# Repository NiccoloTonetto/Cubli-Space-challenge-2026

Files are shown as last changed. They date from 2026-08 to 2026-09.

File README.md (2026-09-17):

# Cubli — Space Challenge 2026

A 156 mm reaction-wheel cube that balances on an **edge** and on a **corner**,
taken from Lagrangian derivation through Simscape multibody simulation to
working hardware — and validated against its own flight telemetry.

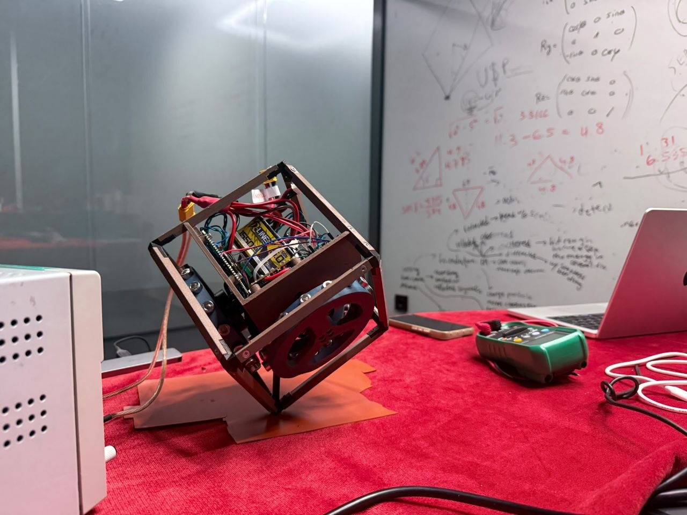
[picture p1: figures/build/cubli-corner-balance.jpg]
The cube balancing unsupported on one corner


*Standing on a single corner, unsupported. Three reaction wheels, a Teensy 4.1
closing a 400 Hz loop, and a gain set designed for this specific corner.*

And the telemetry underneath it — six minutes of exactly that, without falling:

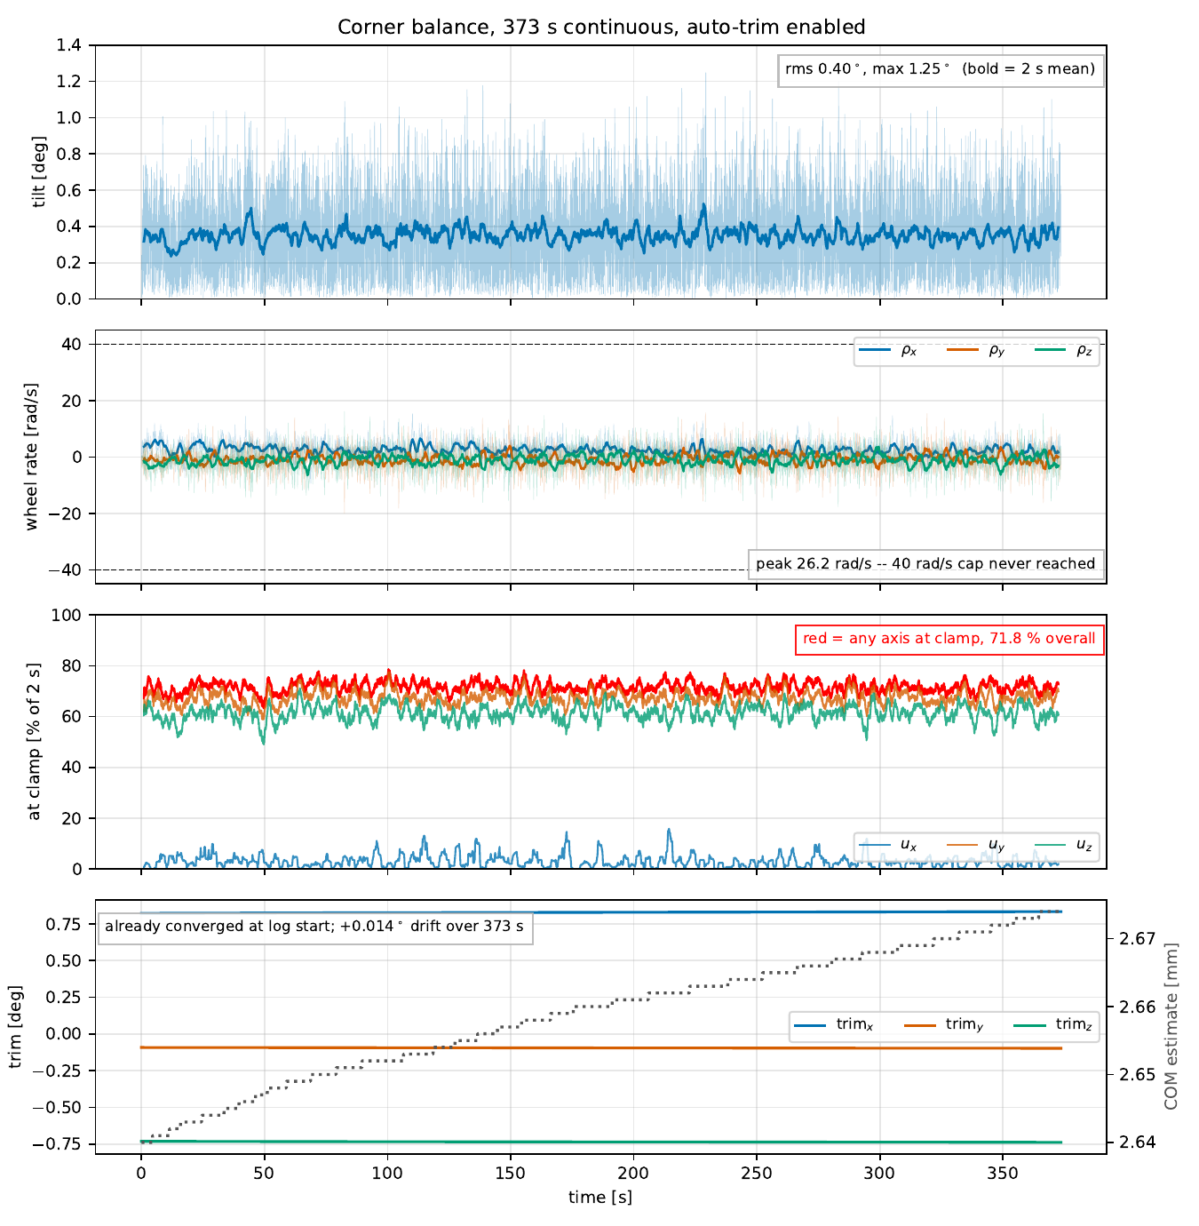
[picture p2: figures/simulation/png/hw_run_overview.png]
373 s of continuous corner balance


*373 s continuous. Tilt RMS 0.40°, peak 1.25°, wheels never reaching the
40 rad/s policy cap. Raw log:
[`data/corner/corner-balance-373s-2026-08-20.log`](data/corner/corner-balance-373s-2026-08-20.log).*

---

## What it achieves

| | Result | Source |
|---|---|---|
| **Corner balance, longest run** | **373.5 s continuous**, tilt RMS **0.40°**, max 1.25° | [log](data/corner/corner-balance-373s-2026-08-20.log) |
| **Corner balance, quietest run** | 278 s, tilt RMS **0.25°**, max 0.92° | [log](data/corner/FINAL_CALIBRATION.log) |
| **Edge balance** | **197 s continuous**, tilt RMS 0.58° | [log](data/edge/1minEDGE.log) · [report](docs/testing/Corner-RateFilter-and-Edge-Hardware-Tests-2026-08-19.md#4-edge--1-min-quiet-hold) |
| **Disturbance rejection** | recovers ~3° pushes in **0.08–0.20 s**; trips at the 25° policy limit | [report §3](docs/testing/Corner-RateFilter-and-Edge-Hardware-Tests-2026-08-19.md#3-pushes--how-hard-until-it-falls) |
| **Edge release** | recovers from **6.18°**, settles under 0.5° by 9.6 s | [report §5](docs/testing/Corner-RateFilter-and-Edge-Hardware-Tests-2026-08-19.md#5-edge--recovery-from-6) |
| **Predicted envelope** | 2.76°–3.14° worst-case recovery, all 8 corners | [envelope study](docs/dynamics/Cube-Performance-Envelope-Results.md#per-corner-results-own-gains-supersedes-part-2-3s-table) |

The hardware sits inside the envelope the simulation predicted, and the run above
is *momentum*-bound rather than torque-bound — exactly the binding constraint the
model identified before the cube was ever switched on.

## The system

| | |
|---|---|
| **Structure** | 156 mm printed PETG-CF frame, 1.615 kg assembled, 3 ballasted reaction wheels |
| **Actuation** | 3 × T-Motor Antigravity 4006 (Kt 0.02513 N·m/A) on 3 × [mjbots moteus-n1](https://mjbots.com) FOC drivers, 5 Mbps CAN-FD |
| **Sensing** | Bosch BMI270 IMU at the cube's geometric centre — 130 mm from *every* corner |
| **Compute** | Teensy 4.1 running the 400 Hz control loop; XIAO ESP32-C6 as a Wi-Fi telemetry bridge |
| **Estimator** | reduced-attitude complementary filter with gyro-bias states (`kP = 4`, `kI = 0.5`) |
| **Control** | per-corner and per-edge reduced-order LQR, yaw-projected — 8 corner gain sets, 12 edge gain sets |
| **Operating point** | τ_max 0.12 N·m, wheel-speed cap 40 rad/s (firmware policy, not a hardware limit) |

## The engineering story

**1 — Derive the plant.** The [3D Lagrangian derivation](docs/dynamics/3D-Cubli-Lagrangian-Derivation.md)
is worked from scratch and specialised to the 1D/2D edge case, with
[CAD → model parameters](docs/dynamics/Deriving-Dynamics-from-CAD.md) and an
[attitude-representation study](docs/dynamics/Quaternions-Complete-Guide.md)
that ends up rejecting quaternions for corner balance and choosing a reduced
attitude instead — [argued, not assumed](docs/dynamics/Attitude-Representation-for-Firmware.md).

**2 — Prove it on a 2D panel first.** A [Simscape panel model](docs/simulation/Simscape-Panel-Model-Build-Guide.md)
with four dedicated nonlinearity studies — [saturation envelope](docs/simulation/reports/Saturation-Envelope-Test-Block-A.md),
[discrete-loop delay](docs/simulation/reports/Discrete-Loop-Test-Block-B.md),
[IMU lever arm](docs/simulation/reports/IMU-Lever-Arm-Estimator-Block-C.md),
[friction sensitivity](docs/simulation/reports/Friction-Sensitivity-Block-D.md).
The [1D-jig-to-3D-cube strategy](docs/dynamics/1D-Jig-to-3D-Cube-Strategy.md)
states exactly what transfers and what does not.

**3 — Build the cube model three ways.** A 9-state linear design plant, a
Simscape multibody model built from imported STEP geometry, and a fast nonlinear
plant with sensors and actuator limits. They agree to
[`A err 1.7e-07`](docs/dynamics/Cube-Performance-Envelope-Results.md#validation-chain)
and within 1 % through the transient — which is what makes the thousands of
bisection runs behind the recovery envelope trustworthy.

<table>
<tr>
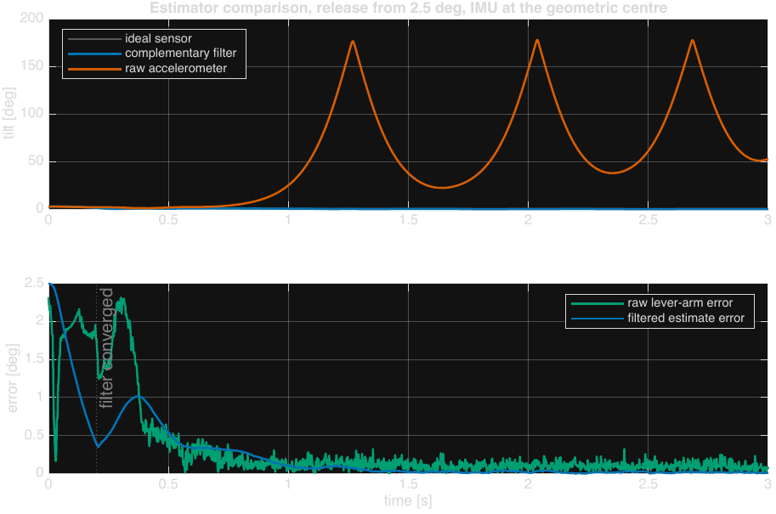
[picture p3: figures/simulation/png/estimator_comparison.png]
Estimator comparison
<td width="50%"></td>
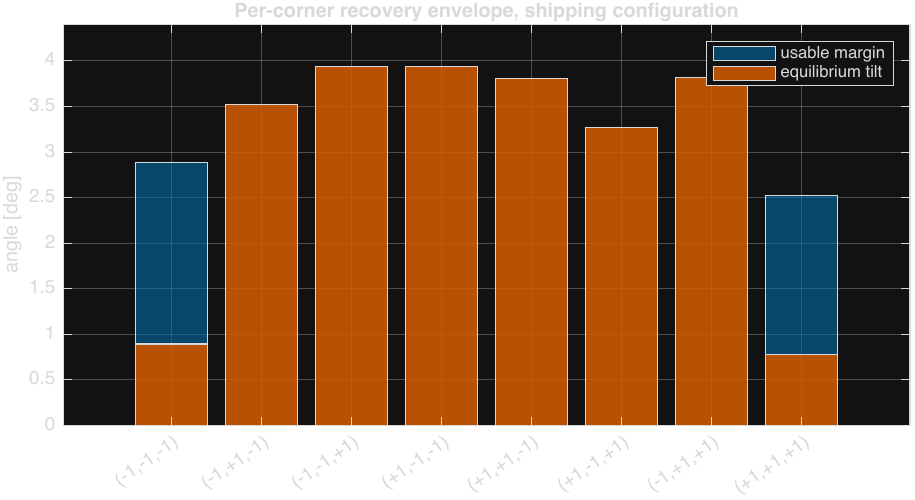
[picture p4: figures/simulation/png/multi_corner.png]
Per-corner recovery envelope
<td width="50%"></td>
</tr>
<tr>
<td><b>The accelerometer lever arm is the dominant sensing effect.</b> Fed raw, the
cube falls every time, at any IMU position. The complementary filter rejects it
almost entirely — but there is a cliff past ~150 mm, which is why the IMU sits at
the geometric centre.</td>
<td><b>All eight corners balance, but each needs its own gains.</b> Apply the
primary corner's gains elsewhere and six corners diverge at the open-loop rate.
The antipodal corner <i>almost</i> works — a 13 s fall that short tests score as
a pass.</td>
</tr>
</table>

**4 — Find the real limits, then design to them.** A 48-point Bryson grid moves
the envelope by 2 %; the [actuator chart](figures/simulation/png/actuator_chart.png)
moves it by 4×. The conclusion — *the envelope is set by hardware, not by the
controller* — is what makes the rest of the project honest about what tuning can
and cannot buy. The shipped weights are chosen on
[robustness to inertia error](figures/simulation/png/qw_robustness.png), not on
peak performance: `qw = 10` costs 4 % against the grid optimum and is the only
set that survives ±20 % on Θ.

**5 — Climb a staged bring-up ladder on hardware.** Every control mode is reached
through the same five stages, each of which must pass before the next is flashed:
open-loop torque → damping only → position + damping → full law → release. The
ladders live in [`firmware/`](firmware/) — [panel](firmware/panel-bringup/),
[cube](firmware/cube-bringup/), [edge](firmware/edge-bringup/),
[corner](firmware/corner-bringup/), and a separate [Wi-Fi link ladder](firmware/link-bringup/).

**6 — Measure, and correct the record when it disagrees.** The
[hardware test reports](docs/testing/) are written to be falsifiable: the
rate-filter A/B is reported as **not a clean comparison** and the reasons are
given; a firmware comment claiming "20–30 dB of attenuation" is shown to be
**~6 dB** with the filter theory to prove a first-order filter cannot do better.
Simulation values that later proved wrong are struck through and corrected in
place rather than quietly edited.

## Repository map

```
├── docs/           theory, design studies and test reports
│   ├── dynamics/       Lagrangian derivation, attitude, CAD→parameters, cube envelope
│   ├── simulation/     panel model build guide + 4 nonlinearity studies + cube envelope
│   ├── testing/        hardware test campaigns, fine-tuning plan
│   ├── electronics/    electrical design guide + schematic PDFs
│   ├── bom/            component reference, motor notes, CAD↔BOM handoff
│   └── references/     literature, with DOIs
├── simulation/     MATLAB + Simulink/Simscape
│   ├── panel-2d/       the 1D/2D panel model and its LQR design
│   ├── cube-3d/        the 3D cube: params, plant, nonlinear sim, Simscape, studies, CAD
│   └── validation/     tools that plot hardware telemetry against the model
├── firmware/       Teensy + XIAO, organised as bring-up ladders
│   ├── panel-bringup/  cube-bringup/  edge-bringup/  corner-bringup/  link-bringup/
│   ├── cubli-ui/       the consolidated final system: firmware, dashboard, tools
│   ├── imu-calibration/  xiao/
│   └── archive/        superseded builds, kept for provenance
├── data/           curated flight telemetry (see data/README.md for formats)
├── figures/        every plot, render and demo video
└── hardware/       KiCad schematic, PCB and project libraries
```

## Reproducing the results

**Simulation** needs MATLAB with Simulink, Simscape and Simscape Multibody, plus
the Control System Toolbox. See [`simulation/README.md`](simulation/README.md)
for the exact run order — several scripts depend on workspace state left by
earlier ones and will tell you so if you skip ahead.

```matlab
addpath(genpath('simulation'))
cubli_demo          % self-contained 3D recovery demo — no Simulink needed
```

**Firmware** is Arduino-IDE / `arduino-cli` sketches for Teensy 4.1 and XIAO
ESP32-C6. Start at [`firmware/README.md`](firmware/README.md); to actually run
the cube, [`firmware/cubli-ui/README.md`](firmware/cubli-ui/README.md) is
self-contained.

## Who did what

This was a two-person build for the Space Challenge Sofia 2026 programme, and the
repository contains both people's work.

**Niccolò Tonetto** — dynamics and all written analysis ([`docs/`](docs/) is
entirely mine): the Lagrangian derivation, attitude-representation study,
CAD-to-parameters method, the 2D panel Simscape model and its four nonlinearity
studies, the 3D cube simulation chain (per-corner plant, reduced-order LQR,
nonlinear sim, recovery-envelope sweeps, figure generation), the electronics —
[schematic, PCB and BOM](hardware/) — and the five-stage bring-up ladder used for
every control mode.

**Pablo Urioste** ([@pablourioste](https://github.com/pablourioste)) — the
telemetry and Wi-Fi stack and the tooling around it: the XIAO bridge, the
[`cubli-ui`](firmware/cubli-ui/) dashboard and analysis tools, the Wi-Fi variants
of the bring-up stages, and IMU calibration.

The `git log` is the authoritative record; `git shortlog -sn` gives the split.

## Status and honest limits

This is a working balance controller, not a finished vehicle. Known gaps, all
documented rather than hidden:

- **Only corner `[-1,-1,-1]` has been flown.** All eight corners are
  geometry-complete and have verified gain designs, but the `Kp` matrices for
  corners 2–8 have not been transcribed into firmware — and running a corner on
  the wrong corner's gains is [worse than not identifying it at all](docs/dynamics/Cube-Performance-Envelope-Results.md#whats-not-re-derived-yet).
- **Multi-corner locomotion is currently off the table on six of eight corners.**
  A structural strut added during bring-up shifted the COM enough that their
  equilibrium tilt now exceeds their own recovery envelope. The analysis is
  [in the repo](docs/dynamics/Cube-Performance-Envelope-Results.md#multi-corner-picture--the-finding-that-matters); the fix is a counterweight, not a gain change.
- **No jump-up.** Balance only — the braking jump-up of the ETH papers was not attempted.
- **Edge balance has no simulation study.** It went straight from estimator design
  to staged hardware bring-up, so its numbers are measured, not predicted, and the
  reports say so.
- **Several plant parameters are still estimates** — wheel Coulomb friction, viscous
  damping and the real continuous-torque limit are flagged `PLACEHOLDER` in
  [`cubli_gains.h`](firmware/cubli-ui/teensy/cubli_gains.h) pending spin-down and
  thermal tests.
- **The wheel-speed cap costs about 20 % of available capability.** Raising it
  requires balanced wheels and a re-run of the gain grid, in that order — it is
  not a constant you can edit.

## References

Full citations with DOIs in [`docs/references/`](docs/references/README.md). The
core prior art is the ETH Zurich Cubli — Gajamohan et al. (IROS 2012, ECC 2013)
and Muehlebach & D'Andrea (IEEE TCST 2017).

## License

Original work in this repository is MIT licensed — see [LICENSE](LICENSE).
Third-party vendor libraries, JavaScript and fonts keep their own licenses —
see [NOTICE](NOTICE).

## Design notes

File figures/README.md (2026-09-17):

# Figures

Every plot, CAD capture and video. Simulation figures are committed as **both**
PDF (vector, for reports) and PNG (raster, so they render inline on GitHub).
Regenerate the whole simulation set with
[`cubli_figures.m`](../simulation/cube-3d/export/cubli_figures.m).

## `build/` — the physical cube

| File | What it shows |
|---|---|
| [`cubli-corner-balance.jpg`](build/cubli-corner-balance.jpg) | The cube balancing unsupported on a single corner. Printed frame, three ballasted reaction wheels, moteus drivers and the Teensy stack visible inside, battery top-centre. This is the README hero. |

## `simulation/` — the design study

| Figure | What it shows |
|---|---|
| [`hw_run_overview`](simulation/png/hw_run_overview.png) | **The headline.** 373 s of continuous corner balance — tilt, wheel rates, torque-clamp duty and trim convergence. Generated from real telemetry, not simulation. |
| [`cube_recovery`](simulation/png/cube_recovery.png) | Corner `(-1,-1,-1)` released from 2.8°, shipping configuration: true tilt against estimate error |
| [`estimator_comparison`](simulation/png/estimator_comparison.png) | Ideal sensor vs complementary filter vs raw accelerometer. The raw trace runs to 200° — it falls every time |
| [`multi_corner`](simulation/png/multi_corner.png) | Per-corner recovery envelope against equilibrium tilt, all eight corners, with the usable margin |
| [`actuator_chart`](simulation/png/actuator_chart.png) | Worst-case recovery across the τ_max × ω_cap design space. The envelope is set here, not by the controller |
| [`qw_robustness`](simulation/png/qw_robustness.png) | Wheel-rate weight vs robustness to inertia error. Gaps are failures — why `qw = 10` ships instead of the grid optimum |
| [`kp_cliff`](simulation/png/kp_cliff.png) | Complementary-filter gain: a hard cliff between 6 and 7, and why the shipped value is 4 |
| [`loop_rate`](simulation/png/loop_rate.png) | Discrete closed-loop damping vs loop rate with one-cycle delay — the stability floor at 38.6 Hz and the 400 Hz design point |
| [`pole_map`](simulation/png/pole_map.png) | Open- and closed-loop eigenvalues |
| [`ctrb_spectrum`](simulation/png/ctrb_spectrum.png) | Controllability matrix spectrum: rank 8 of 9. Yaw is uncontrollable — which is why the gains are yaw-projected |
| [`swing_amplitude`](simulation/png/swing_amplitude.png) | Amplitude error in swing-test inertia measurement, exact vs small-angle |

## `hardware/` — test campaign plots

[`2026-08-19-corner-edge/`](hardware/2026-08-19-corner-edge/) — nine plots
generated from flight telemetry for the
[corner rate-filter and edge hardware tests](../docs/testing/Corner-RateFilter-and-Edge-Hardware-Tests-2026-08-19.md),
which embeds and discusses each one: quiet-hold tilt, wheel effort, PSD and
filter effect, the push-to-failure timeline and a time-aligned zoom, edge quiet
hold, edge recovery from 6°, and a Kalman-vs-complementary PSD comparison.

## `cad/` — mass properties and measurement

| File | What it shows |
|---|---|
| [`params-weighed.jpg`](cad/params-weighed.jpg) | The physical weighing session behind the measured mass properties |
| [`all_cube_data.jpg`](cad/all_cube_data.jpg) | CATIA mass-property readout, full assembly |
| [`wheel_data.jpg`](cad/wheel_data.jpg) | CATIA mass-property readout, reaction wheel |
| [`non_rotational_data.jpg`](cad/non_rotational_data.jpg) | CATIA mass-property readout, non-rotating structure |

These are the bridge between CAD and the model — the method is written up in
[`Deriving-Dynamics-from-CAD.md`](../docs/dynamics/Deriving-Dynamics-from-CAD.md).

## `media/` — video

| File | What it is |
|---|---|
| [`corner-balance-demo.mp4`](media/corner-balance-demo.mp4) | The cube balancing on its corner |
| [`panel-recovery-sim.mp4`](media/panel-recovery-sim.mp4) | Simscape animation of the 2D panel recovering |

## Conventions

- Simulation figures are generated, never hand-edited. If one is wrong, fix the
  script and regenerate.
- PNG renders are produced from the PDFs at 150 dpi:
  `pdftoppm -png -r 150 -singlefile in.pdf out`
- Hardware plots are produced by the analysis tools in
  [`firmware/cubli-ui/tools/analysis/`](../firmware/cubli-ui/tools/analysis/)
  from the captures in [`data/`](../data/README.md).

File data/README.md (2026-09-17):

# Flight telemetry

Curated recordings from the cube and the 2D panel. These are the runs the
[test reports](../docs/testing/) analyse and the runs that firmware constants were
measured from — not a full session archive. Roughly 150 MB of redundant repeats,
zero-length captures and superseded sessions were removed during cleanup.

Every number quoted below was recomputed from the file in this folder, over the
single longest contiguous `armed == 1` window.

## `corner/` — 3-wheel corner balance

| File | Armed | Tilt RMS | Tilt max | What it is |
|---|---|---|---|---|
| [`corner-balance-373s-2026-08-20.log`](corner/corner-balance-373s-2026-08-20.log) | **373.5 s** | **0.40°** | 1.25° | The longest continuous balance. Auto-trim converged; wheels peak at 26 rad/s against a 40 rad/s cap. Plotted in [`hw_run_overview`](../figures/simulation/png/hw_run_overview.png). |
| [`FINAL_CALIBRATION.log`](corner/FINAL_CALIBRATION.log) | 278.1 s | **0.25°** | 0.92° | Quietest run recorded. Its last ~55 s is the source of the hardcoded `kPhiOffset` in `CubliCorner`/`CubliBalance`. |
| [`perfect_equilibrium_2.log`](corner/perfect_equilibrium_2.log) | 101.8 s | 0.33° | 0.99° | The converged-trim run (per-axis std < 0.0012°) that justified retiring trim adaptation for a fixed offset. |
| [`1minCORNER_autotrim.log`](corner/1minCORNER_autotrim.log) | 46.7 s | 0.39° | 0.93° | Quiet hold, **no** rate filter. A-side of the rate-filter comparison. |
| [`1minCORNER_lpf.log`](corner/1minCORNER_lpf.log) | 50.4 s | 0.46° | 1.22° | Quiet hold, 20 Hz rate filter. B-side. 28 columns — carries the filtered rates too. |
| [`PUSHES_CORNER_autotrim.log`](corner/PUSHES_CORNER_autotrim.log) | — | — | 24.0° | Repeated manual pushes to failure, no rate filter. 5 recovered pushes, then the 25° trip. |
| [`PUSHES_CORNER_lpf.log`](corner/PUSHES_CORNER_lpf.log) | — | — | 23.8° | Same, with the rate filter. 4 recovered pushes. |
| [`corner-trim-convergence-2026-08-21.csv`](corner/corner-trim-convergence-2026-08-21.csv) | — | — | — | Short dashboard capture; a small, readable example of the plot-mode CSV. |

> **The two `1minCORNER_*` runs are not a clean A/B.** They are separate bench
> sessions, and the filtered build also shipped a faster trim-adaptation gain.
> [The report says so and explains why](../docs/testing/Corner-RateFilter-and-Edge-Hardware-Tests-2026-08-19.md#1-corner-quiet-hold--autotrim-vs-rate-filter) —
> don't read the delta as the filter's effect.

## `edge/` — single-wheel edge balance

| File | Armed | Tilt RMS | Tilt max | What it is |
|---|---|---|---|---|
| [`1minEDGE.log`](edge/1minEDGE.log) | **197.0 s** | 0.58° | 3.58° | Longest edge hold. Intended as undisturbed, but contains an unexplained ~3.5° excursion between t≈100–135 s — see report §4. |
| [`EDGE6degrees.log`](edge/EDGE6degrees.log) | 10.7 s | 1.30° | 6.18° | Release from −6.18°. A lightly damped ring-down, not a clean recovery: overshoots to +5.05°, settles under 0.5° only at 9.6 s. |
| [`EDGE5degrees.log`](edge/EDGE5degrees.log) | 8.0 s | 0.85° | 5.26° | Release from ~5°, companion to the above. |
| [`EDGE_BALANCE.csv`](edge/EDGE_BALANCE.csv) | — | — | — | Dashboard plot-mode capture of an edge session. |

## `panel/` — 2D panel release tests

Hardware validation of the 1D/2D panel model: release from rest at 7°, 8° and 12°.
Same 10-column schema as the edge format, no header row. Plot them against the
model with [`simulation/validation/panel/plot_validation_csv.py`](../simulation/validation/panel/plot_validation_csv.py).

## Formats

Two wire formats. The analysis tools detect which by counting columns.

**Corner — 26 columns** (28 on rate-filter builds), tab-delimited, header row present:

```
t_ms  phi_x_deg phi_y_deg phi_z_deg   om_x_dps om_y_dps om_z_dps
      rho_x rho_y rho_z                rho_x_lp rho_y_lp rho_z_lp
      tau_x tau_y tau_z                tau_cmd_x tau_cmd_y tau_cmd_z
      armed  gain_scale
      trim_x_deg trim_y_deg trim_z_deg trim_com_mm trim_enabled
      [om_x_filt_dps om_y_filt_dps]    <- 28-column builds only
```

`phi` is the reduced-attitude tilt vector `-cross(gB, ghat)` in body axes, **not**
Euler angles. Tilt magnitude is `norm(phi(1:3))`. `rho` is wheel rate relative to
the body — what the encoder reads — and `_lp` is its low-passed version.

**Edge — 10 columns**, comma- or tab-delimited, header row sometimes absent:

```
t_ms, theta_deg, theta_dot_dps, tau_Nm, tau_cmd_Nm,
      armed, gain_scale, wheel_omega_lp, wheel_pos, wheel_vel
```

`.log` files also carry firmware console output interleaved with the data —
command echoes, arm refusals, trip reasons — on lines beginning with `#`. That is
deliberate: the file is what the serial monitor would have shown. Every parser
here skips `#` lines.

Angles are degrees, rates deg/s, torques N·m, wheel rates rad/s, time
milliseconds since boot.

## Reading them

```bash
python firmware/cubli-ui/tools/analysis/plot_session_csv.py      # newest recording
python firmware/cubli-ui/tools/analysis/fft_tilt_analysis.py       data/corner/1minCORNER_lpf.log
python firmware/cubli-ui/tools/analysis/standing_speed_report.py   data/corner/corner-balance-373s-2026-08-20.log
```

New captures written during a live session land under `firmware/**/telemetry/`,
which is gitignored. Promote a run into `data/` deliberately, and add a row above
saying what it shows.

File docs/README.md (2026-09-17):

# Documentation

Theory, design studies and test reports. Roughly in the order the project went
through them.

## `dynamics/` — the plant

| Document | What it covers |
|---|---|
| [`3D-Cubli-Lagrangian-Derivation.md`](dynamics/3D-Cubli-Lagrangian-Derivation.md) | Full 3D corner-balancing equations of motion, derived from scratch. §8 specialises to the 1D/2D edge case |
| [`Deriving-Dynamics-from-CAD.md`](dynamics/Deriving-Dynamics-from-CAD.md) | Turning CAD mass properties into model parameters — including what to do when print density is unknown |
| [`Quaternions-Complete-Guide.md`](dynamics/Quaternions-Complete-Guide.md) | Attitude representation from first principles |
| [`Attitude-Representation-for-Firmware.md`](dynamics/Attitude-Representation-for-Firmware.md) | Why this project uses a **reduced attitude** rather than a quaternion, and what that costs |
| [`1D-Jig-to-3D-Cube-Strategy.md`](dynamics/1D-Jig-to-3D-Cube-Strategy.md) | Exactly what transfers from the 2D panel to the 3D cube, and what does not |
| [`Cube-Performance-Envelope-Results.md`](dynamics/Cube-Performance-Envelope-Results.md) | **The main simulation result.** Methodology, recovery envelopes, per-corner results, the nonlinearity budget, the estimator study, and the strut re-derivation |

## `simulation/` — the models

| Document | What it covers |
|---|---|
| [`Simulation-Strategies.md`](simulation/Simulation-Strategies.md) | Why three models rather than one, and what each is for |
| [`Simscape-Panel-Model-Build-Guide.md`](simulation/Simscape-Panel-Model-Build-Guide.md) | Building the 2D panel model block by block |
| [`Panel-Controller-Workflow.md`](simulation/Panel-Controller-Workflow.md) | Design workflow from plant to gains |
| [`Cube-Envelope-Methodology-and-Results.md`](simulation/Cube-Envelope-Methodology-and-Results.md) | Cube envelope study, source write-up |
| [`Cube-Performance-Envelope-and-Limits.md`](simulation/Cube-Performance-Envelope-and-Limits.md) | Where the limits come from |
| [`Cube-Final-Configuration-Per-Corner-Results.md`](simulation/Cube-Final-Configuration-Per-Corner-Results.md) | Final configuration, corner by corner |

### `simulation/reports/` — the four nonlinearity studies

Each takes one effect the linear design cannot see, and prices it.

| Report | Question |
|---|---|
| [Block A — Saturation Envelope](simulation/reports/Saturation-Envelope-Test-Block-A.md) | How far can it tip and still come back, with a real actuator? |
| [Block B — Discrete Loop](simulation/reports/Discrete-Loop-Test-Block-B.md) | How slowly can the loop run before delay outruns the unstable pole? |
| [Block C — IMU Lever Arm](simulation/reports/IMU-Lever-Arm-Estimator-Block-C.md) | The accelerometer measures specific force, not gravity. How much does that cost? |
| [Block D — Friction Sensitivity](simulation/reports/Friction-Sensitivity-Block-D.md) | With no friction measurements, how much can the loop tolerate? |

## `testing/` — hardware

| Document | What it covers |
|---|---|
| [`Corner-RateFilter-and-Edge-Hardware-Tests-2026-08-19.md`](testing/Corner-RateFilter-and-Edge-Hardware-Tests-2026-08-19.md) | Six captures analysed: corner quiet-hold A/B, pushes to failure, edge quiet hold, edge recovery. Includes what the data **cannot** answer and why |
| [`Kalman-Filter-Rate-Estimator-Evaluation-2026-08-20.md`](testing/Kalman-Filter-Rate-Estimator-Evaluation-2026-08-20.md) | Evaluating a Kalman rate estimator against the shipped complementary filter |
| [`Corner-Fine-Tuning-Test-Plan.md`](testing/Corner-Fine-Tuning-Test-Plan.md) | The ordered test plan for fine-tuning corner balance |

## `electronics/` and `bom/`

[`Electrical-Design-Guide.md`](electronics/Electrical-Design-Guide.md) — power
tree, grounding, CAN topology and the reasoning behind the schematic, with
rendered [schematic PDFs](electronics/) from the KiCad project in
[`hardware/`](../hardware/).

[`bom/`](bom/) — [full component reference](bom/Component-Reference.md) with
verified-vs-estimate flags per parameter, [motor notes](bom/Motor-TMotor-Antigravity-4006.md),
the [CAD↔BOM handoff](bom/CAD-Handoff-BOM.md) and a
[reference-build checklist](bom/Pennings-Reference-Component-Checklist.md).

## `references/`

[Literature with DOIs](references/README.md) — the ETH Zurich Cubli papers and
the unit-complex-number formulation.

## Also here

[`Firmware-Lessons-2D-Panel-to-3D-Cube.md`](Firmware-Lessons-2D-Panel-to-3D-Cube.md)
— bugs found on the panel, how they were fixed, and which ones are structurally
guaranteed to reappear on the cube.

---

**A note on how these are written.** Where a result was later found to be wrong,
the correction is made *in place and on the record* rather than silently — see
the "Correction on record" blocks in the envelope study, and §1 of the
2026-08-19 test report, which states plainly that its own headline comparison is
confounded and should not be read as a verdict.

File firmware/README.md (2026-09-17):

# Firmware

Teensy 4.1 (control, 400 Hz) and XIAO ESP32-C6 (Wi-Fi telemetry bridge), talking
to three mjbots moteus-n1 drivers over CAN-FD and a Bosch BMI270 IMU.

**To actually run the cube, go straight to [`cubli-ui/README.md`](cubli-ui/README.md).**
That folder is self-contained: the flight firmware, the bridge, the dashboard and
every helper. Everything else here is how it was built.

## The bring-up ladders

Every control mode was reached the same way: five stages, each one flashed and
passed on hardware before the next exists. A stage that fails is a stage that
tells you *which* assumption was wrong, because only one thing changed.

```
Stage 1  open-loop torque     does the motor turn the way I think it does?
Stage 2  damping only         can I make it sluggish without making it unstable?
Stage 3  position + damping   does the tilt signal have the sign and scale I expect?
Stage 4  full law             the real controller, hand-held
Stage 5  release              let go
```

| Ladder | Stages | Target |
|---|---|---|
| [`panel-bringup/`](panel-bringup/) | `OpenLoopTorque` → `DampingOnly` → `PositionDamping` → `FullLaw` (+ `_WiFi`) → `Release` | 1-wheel 2D test panel |
| [`cube-bringup/`](cube-bringup/) | `Stage0_SingleMoteusQuery` → `Stage0b_ThreeMoteusLatency` → `Stage0c_IMUJitter` → `Stage0d_Simultaneous` → `Stage4_FullLaw` | 3-wheel platform validation — **do these before any control** |
| [`edge-bringup/`](edge-bringup/) | `WheelSignCheck` → `RateOnly` → `PositionDamping` → `FullLaw` → `Release` | single-wheel edge balance |
| [`corner-bringup/`](corner-bringup/) | `CornerIDAndPulse` → `RateOnly` → `PositionDamping` → Stage 4 family → Stage 5 family | 3-wheel corner balance |
| [`link-bringup/`](link-bringup/) | `BoardsAlive` → `UartLink` → `WiFiJoin` → `UdpEcho` → `BridgeThroughput` → `RailPower` → `RealFirmware` | the Wi-Fi telemetry link, brought up the same way |

The **Stage 0 series** in `cube-bringup/` is worth a look on its own: before any
controller ran on three wheels, it measured three-driver CAN round-trip latency,
IMU sample jitter, and whether three simultaneous torque commands actually land
together. Those are the numbers that set the 400 Hz loop rate and the 3.5 ms delay
budget the [discrete-loop study](../docs/simulation/reports/Discrete-Loop-Test-Block-B.md)
designed against.

### The Stage 4/5 variants in `corner-bringup/`

Corner balance needed more than one Stage 4, and each variant answers a specific
question rather than being a tuning fork:

| Variant | The question it answers |
|---|---|
| `Stage4_FullLaw` | does the per-corner LQR hold at all? |
| `Stage4_AutoTrim` | can the COM offset be learned online instead of measured? |
| `Stage4_FixedOffset` | once trim converges, can adaptation be retired for a constant? |
| `*_RateFilter` | does low-passing the gyro rate help the ~30 Hz structural mode? |
| `Stage4_FixedOffset_Kalman` | does a Kalman rate estimator beat the complementary filter? |
| `Stage5_*` | the same laws, released |

The answers — including the ones that came out **no** — are in
[`docs/testing/`](../docs/testing/). The rate filter in particular delivers about
6 dB, not the 20–30 dB an early firmware comment claimed.

## Other folders

| Folder | What it is |
|---|---|
| [`cubli-ui/`](cubli-ui/) | the consolidated final system — `CubliBalance.ino` fuses edge and corner into one runtime-switchable sketch, plus the Flask dashboard and analysis tools |
| [`imu-calibration/`](imu-calibration/) | BMI270 offset/scale calibration sketch |
| [`xiao/`](xiao/) | early XIAO Wi-Fi experiments and a laptop-side listener |
| [`archive/`](archive/) | superseded builds kept for provenance — the Wi-Fi-mode PreFINAL tree, the abandoned wireless console with OTA flashing, and the first dashboard |

`archive/` exists because several shipped constants cite the run and the build
they came from. It is history, not a menu — nothing there should be flashed.

## Before you touch the cube firmware

Read [`docs/Firmware-Lessons-2D-Panel-to-3D-Cube.md`](../docs/Firmware-Lessons-2D-Panel-to-3D-Cube.md).
It is the condensed list of bugs found on the panel, how they were fixed, and
which parts of the panel's approach do **not** carry over to three wheels and a
real attitude estimate. Two of them are structurally guaranteed to reappear
per-wheel on the cube.

Two standing hazards, both deliberate:

- **Corner mode has no arm gate.** `a1` arms at any tilt. Place the cube near
  balance and keep a hand on it.
- **`cubli_gains.h` is generated.** Regenerate it with `cubli_export_gains.m`
  ([`simulation/cube-3d/export/`](../simulation/cube-3d/export/)) rather than
  editing constants by hand — the stage sketches read their literals from it so
  there is exactly one source of truth.

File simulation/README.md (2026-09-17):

# Simulation

MATLAB, Simulink and Simscape Multibody models for the 2D panel and the 3D cube.

## Requirements

MATLAB R2023b or newer with **Simulink**, **Simscape**, **Simscape Multibody**
and the **Control System Toolbox**. The `cubli_demo` entry point below needs only
base MATLAB and the Control System Toolbox — no Simulink — and is the fastest way
to see the plant and controller work.

Everything assumes the whole tree is on the path:

```matlab
addpath(genpath('simulation'))
```

## Start here

```matlab
cubli_demo          % 3D cube: plant summary, LQR design, 2° recovery
cubli_demo(3.5)     % ...from 3.5° instead
cubli_demo_anim     % animated version
```

Self-contained, no Simulink, a few seconds. If you only run one thing, run this.

---

## `cube-3d/` — the 3D cube

Two physical builds are modelled. **NEMESIS** (156 mm, 1.615 kg, measured
2026-08-21) is the final one and the one that flew; the earlier cube is kept
because the shipped [`cubli_gains.h`](../firmware/cubli-ui/teensy/cubli_gains.h)
and the [performance-envelope study](../docs/dynamics/Cube-Performance-Envelope-Results.md)
were both generated from it.

| Folder | What's in it |
|---|---|
| `params/` | mass properties, geometry, the eight corner equilibria |
| `plant/` | per-corner and per-edge linear plant; reduced-order LQR with yaw projection |
| `analysis/` | nonlinear plant with sensors and actuator limits; recovery-envelope bisection; attitude helpers |
| `simscape/` | `simscape3d.slx` and the scripts that drive it |
| `studies/` | the sweeps and case studies that produced the published numbers |
| `export/` | generates `cubli_gains.h` for firmware, and the figures |
| `cad/` | the STEP geometry the Simscape model imports |

### Run order — NEMESIS (the flown cube)

```matlab
p = cubli_nemesis_params;              % 1. plant from measured masses + STEP geometry
S = cubli_nemesis_sweep(p, 'grid');    % 2. choose Bryson weights (peak torque is the metric)
[Kp,K,info] = cubli_nemesis_gains(p);  % 3. reduced-order LQR, yaw-projected -> Kp is what firmware uses
C = cubli_nemesis_allcorners(p);       % 4. plant + gains for all eight corners
cubli_nemesis_run                      % 5. closed-loop Simscape run  (slow, ~20 s)
```

Step 5 needs steps 1–3 in the workspace and will assert if they are missing.

### Run order — the earlier cube (reproduces the published envelope)

`corner_case_study.m` is a single control panel for the whole study: edit its
CONFIG block, set the RUN flags, press play. It drives the entire toolchain —
`cubli_cube_params` → `cubli_corner_plant` → `cubli_gains` → `cubli_nlsim` →
`cubli_maxrec` → `cubli_corner_run`. Use it rather than calling the pieces by
hand.

```matlab
edit corner_case_study      % set CONFIG + RUN flags, then run
cubli_figures               % regenerate every figure in figures/simulation/
cubli_export_gains          % regenerate firmware/cubli-ui/teensy/cubli_gains.h
```

> `cubli_gains.h` is a **generated file**. Regenerate it with `cubli_export_gains`
> rather than editing the constants by hand — several firmware stages read their
> literals from it precisely so there is one source of truth.

### A note on the Simscape model

`simscape3d.slx` has three wiring quirks that the run scripts handle and that
will bite anyone driving it directly, all documented in the header of
[`cubli_nemesis_run.m`](cube-3d/simscape/cubli_nemesis_run.m):

1. Mux channels come out **interleaved**, not grouped — the permutation is
   detected at runtime, never assumed.
2. Euler angles are not the reduced attitude; `cubli_ss_patch_attitude` inserts
   the `gB` cross-product block. Without it, yaw runs away.
3. Validation ("Gate 3") must run on the **raw** wiring and the closed loop on the
   **patched** wiring. Checking stability in the wrong configuration is misleading.

---

## `panel-2d/` — the 1D/2D panel

The single-wheel test panel that came first. Its job was to make every modelling
mistake cheap, on a rig that cannot hurt anyone, before the cube existed.

| Script | Purpose |
|---|---|
| `cubli_panel_params.m` | plant parameters — measured masses by default |
| `cubli_panel_simscape_gates.m` | six validation gates against `Cubli_sim.slx` |
| `cubli_panel_saturation.m` | Block A — recoverable-tilt envelope with a real actuator |
| `cubli_panel_discrete.m` | Block B — sample-and-hold plus computational delay |
| `cubli_panel_imu.m` | Block C — accelerometer lever arm and complementary filter |
| `cubli_panel_friction.m` | Block D — friction sensitivity and tolerance thresholds |
| `cubli_lqr_design.m` | standalone LQR design and deployability gates |
| `cubli_panel_demo.m` | quick self-contained demo |

**Run the parameter and LQR sections of `cubli_panel_simscape_gates.m` first.**
Blocks A–D all assert on `p` and `K_lqr` being in the workspace and will tell you
if they are missing. Blocks A and B also need manual edits to the Simulink model
first — each script's header states exactly which blocks to insert and how to wire
them.

Written up in [`docs/simulation/`](../docs/simulation/), with one report per block
under [`reports/`](../docs/simulation/reports/).

---

## `validation/` — model vs hardware

Scripts that plot recorded flight telemetry against the model's prediction.
The matching captures are in [`../data/`](../data/README.md); the 2D panel
release tests at 7°, 8° and 12° are in `data/panel/`.

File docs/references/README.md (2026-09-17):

# References

The literature this project builds on. The PDFs themselves are not redistributed
here — three of the four are IEEE copyright — so each entry below gives the DOI
or arXiv link to fetch it from the publisher.

## Primary — the ETH Zurich Cubli

**[1] The Cubli: A Cube that can Jump Up and Balance**
M. Gajamohan, M. Merz, I. Thommen, R. D'Andrea.
*IEEE/RSJ International Conference on Intelligent Robots and Systems (IROS), 2012*, pp. 3722–3727.
DOI: [10.1109/IROS.2012.6385902](https://doi.org/10.1109/IROS.2012.6385902)

> The 1D prototype. Establishes the reaction-wheel-braking jump-up and the
> single-axis balancing plant this project's [2D panel model](../simulation/Simulation-Strategies.md)
> reproduces.

**[2] The Cubli: A Reaction Wheel Based 3D Inverted Pendulum**
M. Gajamohan, M. Muehlebach, T. Widmer, R. D'Andrea.
*European Control Conference (ECC), 2013*, pp. 268–274.
DOI: [10.23919/ECC.2013.6669562](https://doi.org/10.23919/ECC.2013.6669562)

> The full 3D cube: mechatronic design, multi-body dynamics, frequency-domain
> parameter identification on the edge, and corner balancing by linear feedback.
> This is the closest reference to what is built here, and the source of the
> corner-balance formulation used in [`3D-Cubli-Lagrangian-Derivation.md`](../dynamics/3D-Cubli-Lagrangian-Derivation.md).

**[3] Nonlinear Analysis and Control of a Reaction Wheel-based 3D Inverted Pendulum**
M. Muehlebach, R. D'Andrea.
*IEEE Transactions on Control Systems Technology*, 2017, vol. 25, no. 1, pp. 235–246.
DOI: [10.1109/TCST.2016.2549266](https://doi.org/10.1109/TCST.2016.2549266)

> Backstepping controller with global stability, plus a gradient-based learning
> algorithm for jump-up. The benchmark this project's LQR is deliberately
> *simpler* than — see the estimator roadmap in
> [`Cube-Performance-Envelope-Results.md`](../dynamics/Cube-Performance-Envelope-Results.md)
> for why a quaternion MEKF and a nonlinear law were scoped out for corner
> balance specifically.

## Attitude representation

**[4] The Cubli: Modeling and Nonlinear Control Utilizing Unit Complex Numbers**
F. Bobrow, B. A. Angelico, P. S. P. da Silva. 2020.
arXiv: [2009.14625 [eess.SY]](https://arxiv.org/abs/2009.14625)

> Unit complex numbers for the 1D case, quaternions for the 3D case. Read
> alongside [`Quaternions-Complete-Guide.md`](../dynamics/Quaternions-Complete-Guide.md)
> and [`Attitude-Representation-for-Firmware.md`](../dynamics/Attitude-Representation-for-Firmware.md);
> this project ends up using a *reduced-attitude* formulation (gravity direction
> in body frame) rather than a full quaternion, for the reasons set out there.

## How these are used

The derivations in [`docs/dynamics/`](../dynamics/) are worked from scratch rather
than copied, and the notation is stated locally in each document. Where a result
matches one of the papers above it is cited inline at the point of use; where this
project departs from them — the reduced-attitude estimator, the per-corner gain
tables, the momentum-bound rather than torque-bound operating point — the
departure is argued rather than assumed.

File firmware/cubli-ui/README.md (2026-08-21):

# CubliUI — everything needed to run the cube

One folder: the **Teensy** balance firmware, the **XIAO** Wi-Fi firmware, the
**laptop dashboard**, and every Python helper.

You should not need to look anywhere else in the repo to run the cube.

```
Browser (laptop)  ──►  Python app.py  ──UDP──►  XIAO  ──UART──►  Teensy
   :8000                (your laptop)          bridge
```

---

## 1. What changed

There used to be two UIs and two Teensy binaries. Now there is one of each.

- **MODE B (the wireless console + OTA flashing) is gone.** It was abandoned as
  unreliable. Its source is still in the archive under
  `firmware/3D model/Gam/FINAL/` if you ever need to look at it.
- **Edge and corner are one sketch.** `CubliBalance.ino` holds both control
  laws and switches between them at runtime, so changing what the cube balances
  on is a button, not a re-flash. This is what OTA existed to work around.

---

## 2. Folder map

```
firmware/CubliUI/
│
├── README.md                          ← you are here
│
├── teensy/
│   ├── CubliBalance/CubliBalance.ino  ← FUSION: both laws + m0/m1 ← use this
│   ├── CubliCorner/CubliCorner.ino    ← standalone corner (A/B reference)
│   ├── CubliEdge/CubliEdge.ino        ← standalone edge   (A/B reference)
│   └── cubli_gains.h                  ← simulation-generated constants
│
├── xiao/
│   └── xiao_teensy_bridge/            ← the ONLY XIAO program
│
├── dashboard/
│   ├── app.py                         ← run this
│   ├── schemas.py                     ← wire formats + command whitelist
│   ├── replay.py                      ← desk test with no hardware
│   └── static/                        ← the web UI (+ classic/ fallback)
│
├── tools/
│   ├── terminal_wifi.py               ← serial monitor over Wi-Fi
│   ├── link_check.py                  ← one-shot verdict on the link
│   ├── telemetry_python_wifi.py       ← live matplotlib plots — edge
│   ├── telemetry_python_wifi_corner.py← live matplotlib plots — corner
│   └── analysis/                      ← offline plotters and reports
│
├── docs/
│   ├── WIRING.md                      ← pins, baud, power
│   ├── COMMANDS.md                    ← every command letter
│   └── TELEMETRY_FORMATS.md           ← 10 / 26 column meanings
│
└── telemetry/                         ← recordings land here (created on first run)
    ├── plot/                          ← dashboard + live plotter CSV
    └── serial/                        ← terminal_wifi.py logs
```

---

## 3. Flash the two boards (over USB, Arduino IDE)

| Board | Sketch | Board setting |
|---|---|---|
| **XIAO ESP32-C6** | `xiao/xiao_teensy_bridge/xiao_teensy_bridge.ino` | XIAO_ESP32C6 |
| **Teensy 4.1** | `teensy/CubliBalance/CubliBalance.ino` | Teensy 4.1 |

### The three Teensy targets

`CubliBalance` is the one to run. The other two exist so you can A/B it against
the builds it was fused from — same XIAO firmware, same dashboard, no other
changes.

| Sketch | Balances on | Mode switch | Halt | Use it for |
|---|---|---|---|---|
| **`CubliBalance`** | edge **and** corner | ✓ `m0` / `m1` | ✓ `h1`/`h0` | **normal operation** |
| `CubliCorner` | corner only (3 wheels) | ✗ | ✓ `h1`/`h0` | proving the corner law is unchanged |
| `CubliEdge` | edge only (1 wheel) | ✗ | ✗ **none** | proving the edge law is unchanged |

The two standalone sketches are verbatim copies of the archive references, so
"does the fusion behave identically?" is answerable by flashing each in turn
and comparing. Their headers list exactly which dashboard buttons go quiet
against them (mode switch on both, **halt on `CubliEdge`**). That is expected,
not a fault — those commands only exist in the fused build.

Compile all three without uploading:

```powershell
cd "C:\Users\pablo\OneDrive\Documentos\GitHub\Cubli-Space-challenge-2026\firmware\CubliUI"
foreach ($s in "CubliCorner","CubliEdge","CubliBalance") {
  arduino-cli compile -b teensy:avr:teensy41 "teensy/$s"; "$s -> $LASTEXITCODE"
}
```

Set your Wi-Fi in the XIAO sketch before uploading:

```cpp
const char* WIFI_SSID     = "cubli1";
const char* WIFI_PASSWORD = "your-password";
```

Once flashed you should not need to touch the XIAO again — mode, gain, trim and
arming are all runtime commands.

> ⚠ **Corner mode has no arm gate.** `a1` arms at any tilt. Place the cube near
> balance first and keep a hand on it. See `docs/COMMANDS.md`.

---

## 4. Run the dashboard

Once, to install:

```powershell
cd "C:\Users\pablo\OneDrive\Documentos\GitHub\Cubli-Space-challenge-2026\firmware\CubliUI\dashboard"
pip install -r requirements.txt
```

Then, every session — **close anything else using UDP 4210 first** (the
plotters, `terminal_wifi.py`):

```powershell
cd "C:\Users\pablo\OneDrive\Documentos\GitHub\Cubli-Space-challenge-2026\firmware\CubliUI\dashboard"
python app.py
```

Open **http://127.0.0.1:8000**. Your laptop must be on the same Wi-Fi as the
XIAO.

| Route | UI |
|---|---|
| `/` | Minimal console — arm/disarm, mode switch, status, charts, LQR gain sliders |
| `/classic` | The previous Tailwind dashboard, kept as a fallback |

Useful flags:

```powershell
python app.py --read-only        # monitor mode: arming and mode switch blocked
python app.py --port 8080        # different web port
```

### Confirm it works

| Check | Expected |
|---|---|
| Link pill | shows a rate, not `NO LINK` |
| State pill | `DISARMED · CORNER` (or `· EDGE`) |
| Charts | moving |
| E-STOP | always available |

If nothing arrives:

```powershell
cd "..\tools"
python link_check.py
```

---

## 5. Driving the cube

Full grammar in `docs/COMMANDS.md`. The short version:

| Button | Sends |
|---|---|
| EDGE / CORNER | `m0` / `m1` — **always disarms first** |
| ARM | `a1` (two-step confirm) |
| E-STOP / DISARM | `a0` — also **spacebar** |
| Re-resolve pivot | `c` (corner) / `e` (edge) |
| Halt / Resume | `h1` / `h0` |
| Gain slider | `g<0..1>` |
| Edge trim | `o<deg>` (edge mode only) — **on top of** the hardcoded `-0.7°` default |
| Reset trim to default | sends `o-0.70` (edge mode only) |
| Tilt / Rate / Wheel gain sliders | `p<0..3>` / `r<0..3>` / `w<0..3>` — live-scale this mode's own LQR gain terms, default `1.0`. No 3D view any more; these sliders + the trimmed Tilt/Wheel charts replaced it. |

A typical corner session:

```
place the cube on the corner  →  CORNER  →  Re-resolve  →  gain 0.5  →  ARM
```

---

## 6. Proving the fusion is faithful (A/B on the bench)

Cube **held by hand**, wheels clear, `g0.3`, a finger on the spacebar. Same
XIAO firmware and same dashboard throughout — only the Teensy sketch changes.

> ⚠ `CubliCorner` and `CubliEdge` are **frozen verbatim copies** of the archive
> reference sketches — they predate the hardcoded `-0.7°` edge offset and the
> `p`/`r`/`w` LQR gain sliders, and always will (that's the point of keeping
> them as a faithful reference). `CubliEdge` still boots at `o0` and `CubliBalance`
> now boots at `o-0.70`, so **Round 2 and Round 3's edge `|φ|` will legitimately
> differ by about 0.7°** — that is the new default doing its job, not a fusion
> bug. Send `o0` on `CubliBalance` first if you want a true apples-to-apples
> comparison against Round 2.

**Round 1 — `CubliCorner`.** Place on the corner → Re-resolve → note the
resolved corner name and the resting `|φ|` → ARM briefly → DISARM. Record those
two numbers.

**Round 2 — `CubliEdge`.** Place on the edge → Re-resolve → note the resolved
edge name and resting `|φ|` → ARM (must refuse outside the gate) → DISARM.
Confirm HALT does nothing — that is this build having no halt command.

**Round 3 — `CubliBalance`.** Now both, without re-flashing:

1. Boot shows `# state=DISARMED mode=CORNER armed=0 halted=0`.
2. Corner: Re-resolve → **same corner name and resting `|φ|` as round 1**.
   ARM → `# state=CORNER_BALANCE`. DISARM.
3. Press **EDGE**. Watch, in order: the cube disarms, `# state=DISARMED
   mode=EDGE`, the packet width drops 26 → 10, the dashboard rolls to a new
   CSV, and the two inactive wheels stop.
4. Edge: Re-resolve → **same edge name and resting `|φ|` as round 2**. ARM →
   must refuse outside the gate exactly as it did in round 2.
5. Press **CORNER** and confirm it goes back cleanly.
6. While ARMED, confirm the mode buttons are greyed out.

Matching pivot names and resting `|φ|` across rounds is the real check: it
means the estimator, mount DCM and candidate tables survived the fusion. If
round 3 disagrees with rounds 1–2, the fusion changed something it should not
have — the control paths were copied verbatim, so suspect the mode dispatch in
`loop()` or the renames in the sketch's SECTION 0b before suspecting the law.

---

## 7. Desk test with no hardware

```powershell
# terminal 1
cd "...\CubliUI\dashboard"
python app.py --target 127.0.0.1 --target-port 4211

# terminal 2
python replay.py
```

`--target-port 4211` is required on loopback, otherwise the server talks to its
own bound port and every button looks dead.

Expected quirk: the state pill stays DISARMED and ARM behaves as if far from
equilibrium, because the recorded run has `armed = 0` and starts well off
balance.

`replay.py` needs a recording in `telemetry/plot/`. There are none there yet —
either make one from a live session, copy a `telemetry_corner_*.csv` in from
`firmware/3D model/Gam/PreFINAL/telemetry/plot/`, or use
`python replay.py --schema edge`, which synthesizes a 10-field stream and needs
no file at all.

---

## 8. Other tools

Run these **instead of** `app.py` — they compete for the same UDP port.

```powershell
cd "C:\Users\pablo\OneDrive\Documentos\GitHub\Cubli-Space-challenge-2026\firmware\CubliUI\tools"
```

| Command | Purpose |
|---|---|
| `python terminal_wifi.py` | Serial-monitor over Wi-Fi; type commands directly |
| `python telemetry_python_wifi_corner.py` | Live matplotlib plots — **corner** |
| `python telemetry_python_wifi.py` | Live matplotlib plots — **edge** |
| `python link_check.py` | One-shot verdict on the link |

Each live plotter only parses one mode's format, so switching the cube to the
other mode makes its window go quiet. That is the other mode talking, not a
fault.

### Offline analysis

```powershell
cd "...\tools\analysis"
python plot_session_csv.py          # no args + press d = newest recording
python fft_tilt_analysis.py <file.csv>
python standing_speed_report.py <file.csv>
```

---

## 9. Wi-Fi settings

Baked into the XIAO sketch:

| Setting | Value |
|---|---|
| SSID | `cubli1` |
| Password | set it yourself in the `.ino` |
| XIAO IP | `172.20.10.14` |
| Gateway | `172.20.10.1` |
| UART to Teensy | **1 000 000 baud** |

**Do not change the baud** unless you change `kLinkBaud` in the Teensy sketch
too. A mismatch is silent and looks exactly like a dead cable.

---

## 10. Known rough edges

| Thing | Status |
|---|---|
| Edge arm gate reads 9.58°, comment says 0.5° | Carried forward verbatim on purpose; suspected typo, fix it deliberately with a bench check |
| Corner mode has no arm gate at all | By design. Operator discipline, not a bug |
| `gEdgeAxis` has no command letter | Edge mode is Y-only in practice |
| Edge offset (`-0.7°`) is hand-measured, not converged | No live auto-trim exists for edge yet (deliberately not built); re-measure and update `kEdgePhiOffsetDefaultDeg` by hand if the mount changes |
| `p`/`r`/`w` gain scales have no live readback | The UI shows the last value you sent, not a value read from the cube — same limitation the gain and trim controls already had |
| Battery gauge | No wire format carries voltage; the UI shows link health instead |
| Velocity caps | Bring-up values in both modes, not the Stage 5 policy numbers |

---

## 11. Where the old files live

Nothing was deleted from the archives.

| Old location | Still there? |
|---|---|
| `firmware/3D model/Gam/PreFINAL/` | ✓ full archive — the edge reference build |
| `firmware/3D model/Gam/FINAL/` | ✓ full archive — the corner reference build, the old wireless console, your logs |

`CubliBalance.ino` is a **fusion** of two of those sketches, not a move.
`CubliCorner` / `CubliEdge` are verbatim copies of them. The originals are
untouched: retune there, then re-copy.

---

## 12. Read next

| Question | File |
|---|---|
| How do I wire it? | `docs/WIRING.md` |
| What does `a1` / `m0` / `g0.5` do? | `docs/COMMANDS.md` |
| What are the telemetry columns? | `docs/TELEMETRY_FORMATS.md` |
| How does the mode switch actually work? | `teensy/CubliBalance/CubliBalance.ino` header |

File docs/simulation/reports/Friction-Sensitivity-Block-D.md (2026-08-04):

---
tags:
  - space-challenge
  - sofia
  - cubli
  - simulation
  - panel
  - controls
  - friction
  - firmware
  - validation
---

# Friction Sensitivity — Block D

Fourth nonlinear test. Unlike A–C this one runs **without any measurement**, so
the question is inverted:

> Not *"what does our friction do"* but **"how much friction can the loop
> tolerate before it matters"** — producing thresholds to measure against.

Script: `cubli_panel_friction.m`
Depends on: `cubli_panel_params.m` (measured mode) and the LQR cell of
`cubli_panel_simscape_gates.m`.

---

## 1 — Three mechanisms, three different effects

They are not interchangeable. Two hurt, one helps.

### 1.1 Pivot Coulomb — τ_cp — external, on the panel

Creates a **stick deadband**. Below a threshold tilt the friction torque exceeds
the gravity torque, so the panel simply does not move — and a controller that
sees no motion gets no information.

$$\theta_{dead} = \arcsin\!\left(\frac{\tau_{cp}}{Sg}\right)$$

| τ_cp | % of τ_cont | Deadband |
|---|---|---|
| 0.5 mN·m | 0.4 % | 0.11° |
| 1 mN·m | 0.8 % | 0.22° |
| 2 mN·m | 1.7 % | 0.44° |
| 5 mN·m | 4.2 % | 1.09° |
| 10 mN·m | 8.3 % | 2.18° |

Symptom: **stick-slip limit cycling.** The panel drifts to the deadband edge,
sticks, the controller winds up, it breaks free, overshoots, sticks again.

Our pivot is a steel pin in a printed bracket, so this is not negligible.

### 1.2 Wheel Coulomb — τ_cw — internal, wheel-to-panel

Bearing drag **plus cogging torque**. Worst at zero crossings: the wheel does
not respond to small commands, so fine control near equilibrium degrades. This
is normally the one that bites.

A 12-pole-pair outrunner like the MN4006 can easily show **5–15 mN·m of
cogging**, i.e. **4–12 % of τ_cont**. Cogging appears at 24 cycles per
revolution (2 × pole pairs).

### 1.3 Wheel viscous — b_w — internal, speed-proportional

**Beneficial.** A passive momentum sink that unwinds the wheel with time
constant $I_w/b_w$, costing a little authority in exchange for drift immunity.

| b_w [N·m·s/rad] | Bleed time constant | Drag at ω_cap |
|---|---|---|
| 1e-6 | 186 s | 0.04 mN·m |
| 1e-5 | 18.6 s | 0.40 mN·m |
| 5e-5 | 3.7 s | 2.00 mN·m |
| 2e-4 | 0.9 s | 8.00 mN·m |

Relevant to the Block C finding: gyro bias drives a **standing wheel speed**.
Viscous drag bleeds that passively, for free, with no estimator.

---

## 2 — Equations

Pivot friction is **external** (acts on the panel against ground). Wheel
friction is **internal** (equal and opposite between wheel and panel), so it
enters exactly where the motor torque does:

$$\ddot\theta = \frac{Sg\sin\theta + \tau_p - u - \tau_w}{\bar\Theta}, \qquad
\ddot\phi = \frac{u + \tau_w}{I_w} - \ddot\theta$$

with

$$\tau_p = -\tau_{cp}\tanh(\dot\theta/\varepsilon), \qquad
\tau_w = -\left(b_w\dot\phi + \tau_{cw}\tanh(\dot\phi/\varepsilon)\right)$$

> [!note] Why `tanh` and not `sign`
> A true `sign()` is discontinuous at zero velocity and makes the solver hunt —
> the same failure as the hard wheel-speed cap in [[Saturation Envelope Test — Block A]].
> `tanh(v/ε)` with ε = 0.05 rad/s is a smooth approximation. It slightly
> understates stiction very near zero, so the results are marginally
> **optimistic** on the Coulomb terms.

Pure MATLAB with RK4, same as Block C. Runs are **20 s**, not 5 — stick-slip
limit cycles are slow and would hide inside a short run.

---

## 3 — What the script does

```
runfric()          one run at given (tau_cp, tau_cw, b_w)
   |
   +-- 1. pivot Coulomb sweep     0 .. 20 mNm
   +-- 2. wheel Coulomb sweep     0 .. 40 mNm
   +-- 3. wheel viscous sweep     0 .. 1e-3
   +-- 4. envelope vs friction    4 named cases, bisected
   +-- 5. limit-cycle time plots
```

Metrics returned per run, all computed over the **last half** of the trajectory
so the initial recovery does not contaminate them:

| Field | Meaning |
|---|---|
| `th_ss` | mean steady tilt — non-zero means a deadband offset |
| `phid_ss` | mean steady wheel speed — the momentum cost of friction |
| `lc_amp` | half peak-to-peak tilt — **limit-cycle amplitude** |
| `ok` | survived 20 s with \|θ\| < 2° |

`lc_amp` is the important one. A run can score `ok = true` while hunting
±1° forever, which is a fail in practice even though it never falls over.

---

## 4 — Results

*(fill from the run — table shape below)*

### 4.1 Pivot Coulomb

| τ_cp [mN·m] | % τ_cont | Deadband | θ_ss | φ̇_ss | ok |
|---|---|---|---|---|---|
| 0 | 0 | 0.00° | | | |
| 0.5 | 0.4 | 0.11° | | | |
| 1 | 0.8 | 0.22° | | | |
| 2 | 1.7 | 0.44° | | | |
| 5 | 4.2 | 1.09° | | | |
| 10 | 8.3 | 2.18° | | | |
| 20 | 16.7 | 4.39° | | | |

### 4.2 Wheel Coulomb

| τ_cw [mN·m] | % τ_cont | θ_ss | φ̇_ss | LC amplitude | ok |
|---|---|---|---|---|---|
| 0 … 40 | | | | | |

### 4.3 Wheel viscous

| b_w | Bleed τ | Drag at cap | θ_ss | ok |
|---|---|---|---|---|
| 0 … 1e-3 | | | | |

### 4.4 Recoverable tilt

| Case | τ_cp | τ_cw | b_w | Edge |
|---|---|---|---|---|
| frictionless | 0 | 0 | 0 | (11.5° from Blocks A–C) |
| light | 1 mN·m | 2 mN·m | 1e-5 | |
| moderate | 3 mN·m | 8 mN·m | 5e-5 | |
| heavy | 8 mN·m | 20 mN·m | 2e-4 | |

---

## 5 — Expected behaviour (to check against)

Written before the run, so the results either confirm or surprise:

- **Pivot Coulomb tolerable to ~5 mN·m.** Beyond that the 1°+ deadband should
  produce visible stick-slip.
- **Wheel Coulomb tolerable to ~10 mN·m** before a limit cycle appears. This is
  uncomfortably close to plausible cogging (5–15 mN·m), so it may well be the
  binding mechanism.
- **Envelope drops ~1° in the "moderate" case**, from 11.5° to ~10.5°.
- **Viscous friction should show no downside** across the whole sweep, and
  should reduce `phid_ss`.

If wheel Coulomb turns out above ~20 mN·m, expect the panel to hunt around
vertical rather than settle — balanced but visibly nervous, which reads badly
in a demo even though it technically passes.

---

## 6 — How to measure each, cheaply

All three are moteus-native. Together they take under an hour and turn this
sensitivity study into a prediction.

### 6.1 Pivot Coulomb — static breakaway

Clamp the wheel. Tilt the panel **slowly** by hand and find the angle at which
it just begins to move on its own. Then

$$\tau_{cp} = Sg\sin\theta_{break} = 0.2623\sin\theta_{break}$$

A protractor and two minutes. Repeat both directions — asymmetry indicates a
bent pin or a misaligned bracket.

### 6.2 Wheel Coulomb **and** viscous — spin-down

Command a wheel speed, cut torque, log ω(t) to a stop.

- **Coulomb** gives a **linear** decay (constant deceleration)
- **Viscous** gives an **exponential** decay

Fit both at once:

$$\dot\omega = -\frac{b_w\omega + \tau_{cw}}{I_w}$$

One test, both constants. Do it from a high speed so the exponential region is
well resolved before the linear tail takes over.

### 6.3 Cogging — slow rotation

Position-control the wheel through one revolution at low speed, log current.
Ripple at **24 cycles/rev** (2 × 12 pole pairs) is cogging; amplitude × Kt
(0.02513 N·m/A) gives the torque.

Note the moteus calibration already characterises some of this — worth checking
whether its stored table can be read out rather than re-measuring.

---

## 7 — Design implications

**If pivot friction is high**, it is a *mechanical* fix, not a control one. A
better bearing surface at the pivot, or a proper ball bearing instead of a pin
in printed plastic. No amount of gain tuning removes a deadband — the
information simply is not there.

**If wheel Coulomb is high**, options in order of cost:
1. Accept the limit cycle if amplitude is small — it is cosmetic, not a failure
2. Add a small dither, or a friction feedforward term of magnitude τ_cw
3. Confirm the moteus cogging compensation is enabled

**Viscous friction should be welcomed, not minimised.** It is the only passive
mechanism that unwinds the wheel. Worth remembering when someone proposes
better bearings "to reduce losses" — losses here are 0.4 mN·m against a 120
mN·m budget, and they buy real drift immunity.

---

## 8 — Caveats

- **`tanh` regularisation understates stiction near zero.** Results are
  optimistic on both Coulomb terms.
- **No Stribeck effect.** Real friction has a velocity-dependent dip between
  static and kinetic — worse stick-slip than modelled.
- **Static ≠ kinetic.** Modelled as one coefficient; breakaway is typically
  20–50 % higher than sliding.
- **Cogging modelled as constant Coulomb**, not as ripple at 24 cycles/rev.
  Adequate for a threshold study, wrong for predicting the ripple spectrum.
- **Perfect state knowledge.** Not combined with the Block C estimator; the two
  effects likely interact, since a deadband offset looks like a tilt bias.
- **Friction is temperature and wear dependent.** Whatever is measured on day
  one will drift.

---

## 9 — Open items

- [ ] Run the script, fill §4
- [ ] Breakaway test → τ_cp
- [ ] Spin-down test → τ_cw and b_w
- [ ] Re-run with measured values, compare to the tolerance thresholds
- [ ] Combine with the Block C estimator — deadband plus gyro bias may compound
- [ ] Check whether the moteus cogging table can be read out

---

## Related

- [[Saturation Envelope Test — Block A]] — actuator authority, and the
  `tanh` regularisation precedent
- [[Discrete Loop Test — Block B]] — loop rate
- [[IMU Lever Arm & Estimator — Block C]] — gyro bias and the standing wheel
  speed that viscous friction helps bleed
- [[Firmware Handoff — Panel Stage]] — the measurement procedures in §6 belong
  in Andrea's test plan
- [[Simscape Panel Model — Build Guide]] — §6.6

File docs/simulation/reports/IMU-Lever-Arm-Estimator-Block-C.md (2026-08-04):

---
tags:
  - space-challenge
  - sofia
  - cubli
  - simulation
  - panel
  - controls
  - estimator
  - imu
  - firmware
  - validation
---

# IMU Lever Arm & Estimator — Block C

Third nonlinear test. Answers: **can we actually measure the tilt we are
controlling?**

**Result: yes, with a complementary filter — and the constraint turns out to be
gyro bias, not IMU mounting position.**

Script: `cubli_panel_imu.m`
Depends on: `cubli_panel_params.m` (measured mode) and the LQR cell of
`cubli_panel_simscape_gates.m`.

---

## 1 — The physical problem

An accelerometer does **not** measure gravity. It measures **specific force** —
the difference between the acceleration of the case and free fall. Sitting on a
table, the table pushes up at 1 g, so it reads 1 g upward and we interpret that
as "down is that way". The instant the case accelerates for any *other* reason,
that reading is contaminated.

Our case is bolted to a panel rotating about a pivot. Put the IMU a distance
$d$ from the pivot and it experiences two extra accelerations:

$$\underbrace{\ddot\theta\,d}_{\text{tangential}} \qquad\qquad \underbrace{\dot\theta^2 d}_{\text{centripetal}}$$

so the specific force in body axes is

$$f_x = \ddot\theta\,d + g\sin\theta, \qquad f_y = g\cos\theta - \dot\theta^2 d$$

and a naive tilt readout is $\hat\theta = \operatorname{atan2}(f_x, f_y)$.

### Why this is worse than it sounds

The $\ddot\theta d$ term is **largest exactly when the estimate matters most.**
When the panel is upright and still, $\ddot\theta = 0$ and the accelerometer is
perfect. When the controller is fighting hardest — mid-recovery — $\ddot\theta$
peaks and the accelerometer lies worst.

From the Block A envelope edge, $\ddot\theta$ reaches **−45.6 rad/s²**:

| IMU distance from pivot | Apparent tilt error |
|---|---|
| 10 mm | 2.6° |
| 20 mm | 5.2° |
| 50 mm | 12.9° |
| 106 mm (panel centre) | **25.9°** |

At the panel centre, during a 10° recovery, the accelerometer reports **26° of
tilt in the wrong direction** — an error larger than the disturbance being
corrected. Feed that to the controller and it pushes the wrong way, hard.

The centripetal term is secondary: at $\dot\theta = 3$ rad/s it is under 10 % of
$g$ even at the panel centre.

---

## 2 — The three configurations tested

| Mode | Tilt estimate | Rate estimate |
|---|---|---|
| **truth** | perfect $\theta$ | perfect $\dot\theta$ |
| **naive** | $\operatorname{atan2}(f_x,f_y)$ | gyro |
| **compfilter** | see below | gyro |

The complementary filter, one line:

```matlab
alpha  = tau/(tau + Ts);
th_hat = alpha*(th_hat + gyro*Ts) + (1-alpha)*th_acc;
```

**Read it as two sensors covering two frequency bands.** The gyro is integrated
forward — accurate over short intervals, but drifts because any bias
accumulates. The accelerometer has no drift — it always knows where down is on
average — but is corrupted by $\ddot\theta d$ at high frequency. So: trust the
gyro fast, trust the accelerometer slow. $\tau$ is the crossover.

The lever-arm error is a *transient* lasting ~0.2 s. A filter with $\tau = 1$ s
rejects it almost entirely.

### Simulation note

This block is **pure MATLAB**, not Simscape — the same 3-state nonlinear plant
integrated with RK4. Gate 3 already proved the two agree to 1.7e-07, so for
parameter sweeps the MATLAB version is equivalent and runs in seconds rather
than minutes. Saturation and the wheel cap are carried over from Block A.

Sensor placeholders used (**to be replaced with BMI270 measurements**):
accelerometer 0.02 m/s² rms, gyro noise 0.002 rad/s rms, gyro bias 0.005 rad/s.

---

## 3 — Results

### 3.1 Estimator comparison, d = 50 mm, τ = 1 s, θ₀ = 5°

| Mode | θ_end | Max estimate error | Recovered |
|---|---|---|---|
| perfect state | 0.00° | 0.00° | yes |
| **naive accel** | **88.83°** | **32.44°** | **NO** |
| complementary filter | 0.01° | 0.29° | yes |

The naive case fails outright — the panel ends up on its side. This is the
counterfactual worth keeping: it shows the filter is doing real work.

### 3.2 Recovery envelope with the estimator in the loop

| Configuration | Edge |
|---|---|
| Perfect state | 11.59° |
| Complementary filter | **11.53°** |

**A 0.5 % penalty.** The envelope from Blocks A and B survives.

### 3.3 IMU mounting position sweep — the surprise

| d [mm] | 0 | 10 | 20 | 30 | 50 | 75 | 106 |
|---|---|---|---|---|---|---|---|
| Max est. error | 0.29° | 0.29° | 0.29° | 0.29° | 0.29° | 0.29° | 0.37° |

**Mounting position makes essentially no difference.**

### 3.4 Filter time constant sweep, d = 50 mm

| τ [s] | 0.05 | 0.10 | 0.30 | **1.00** | 3.00 | 10.00 |
|---|---|---|---|---|---|---|
| Max est. error | 1.39° | 1.01° | 0.50° | **0.29°** | 0.70° | 1.13° |

U-shaped, with a shallow optimum around 0.5–1 s.

---

## 4 — Discussion

### 4.1 Why the lever arm stopped mattering

This is the key insight of the block. The error floor of 0.29° is **not** the
lever arm. It is:

$$\text{gyro bias} \times \tau = 0.005 \times 1.0 = 0.005\ \text{rad} = 0.286°$$

which matches the observed 0.29° to two decimals, at every mounting distance.

The filter has already pushed the lever-arm contribution *below the bias floor*.
So the constraint has moved from **mechanical** to **sensor calibration**.

> [!important] Practical consequence
> **Mount the BMI270 wherever is convenient.** Cable routing, board space,
> keeping it off the motor for thermal reasons — all of these now outrank
> proximity to the pivot. What you cannot do is ignore gyro bias.

This also explains the U-shape in §3.4: below τ ≈ 0.3 s the lever arm and
accelerometer noise leak through; above τ ≈ 1 s the bias term $b\tau$ takes
over. The optimum is where the two cross.

### 4.2 What gyro bias actually costs

A constant tilt-estimate error $e$ means the controller drives the *estimate* to
zero, so the panel physically balances $e$ off true vertical. Solving the
steady state ($u = 0$, $\theta = 0$):

$$\dot\phi_{ss} = -\frac{K_1 e}{K_3}$$

| Gyro bias | τ = 0.3 s | τ = 1.0 s |
|---|---|---|
| 0.005 rad/s (0.29°/s) — assumed | 0.95 rad/s (2 %) | 3.17 rad/s (8 %) |
| 0.017 rad/s (1°/s) — **uncalibrated BMI270** | 3.24 rad/s (8 %) | **10.79 rad/s (27 %)** |
| 0.035 rad/s (2°/s) | 6.67 rad/s (17 %) | **22.22 rad/s (56 %)** |

The 0.005 rad/s placeholder is **optimistic**. An uncalibrated consumer MEMS
gyro typically shows 1–2°/s of zero-rate offset. At 1°/s with τ = 1 s you burn
**27 % of the momentum budget standing perfectly still**, before any disturbance
arrives — and that comes straight off the 11.5° envelope.

> [!note] The wheel settles, it does not ramp
> Note the wheel reaches a *steady* speed rather than accelerating to
> saturation. That is the momentum penalty $Q_{33}$ doing its job. With $Q_{33}$
> too small there would be no equilibrium and you would get the classic
> "balances for eight seconds, then falls over" failure.
> See [[Disturbance Estimation & Attitude Representation]].

### 4.3 Do we need an online bias estimator? — No, for the panel

| | Bias | Tilt error (τ=1 s) | Standing φ̇ | % of cap |
|---|---|---|---|---|
| Uncalibrated | 1°/s | 0.97° | 10.8 rad/s | 27 % |
| **Startup calibration** | ~0.05°/s | 0.05° | 0.55 rad/s | **1.4 %** |
| Online estimation | ~0.01°/s | 0.01° | 0.11 rad/s | 0.3 % |

**Startup calibration buys a 20× improvement. Online estimation buys another 5×
on top of something already negligible.** Bad return for the effort at this
stage.

**Startup calibration:** hold the panel still for 2–3 s at boot, average the
gyro, subtract from every subsequent reading. Five lines.

**Where it stops being enough:** thermal drift. The BMI270 sits near a motor
dissipating several watts with no airflow, and MEMS gyro bias moves with
temperature — plausibly 0.1–0.3°/s over a ten-minute session. That puts you back
at 2–6 rad/s standing wheel speed. Acceptable for a demo, a problem for extended
running.

**So: panel → startup calibration. Cube → online estimation**, which is already
the plan (3 gyro-bias states in the 6-state MEKF). A 2-state panel filter
(tilt + bias) would be a cheap way to prototype that architecture on the easier
problem, but it is not needed to pass.

### 4.4 A free diagnostic

A non-zero standing wheel speed has two possible causes: **gyro bias** or a
**COM offset**. They are separable in fifteen seconds:

> Rotate the panel 180° about the pivot axis and re-run.
> A COM offset **reverses sign**. A gyro bias **does not**.

That tells you whether to recalibrate or to shim. It is the diagnostic use of
the disturbance estimate from the sizing notes, in its simplest possible form,
and it needs no estimator at all.

---

## 5 — What Andrea needs from this

1. **Mount the IMU wherever is convenient.** Position is no longer a constraint.
   Prioritise thermal isolation from the motor and clean cable routing.
2. **Startup gyro calibration is mandatory**, not optional. Without it, 27 % of
   the momentum budget is gone before the panel is even disturbed.
3. **Complementary filter, τ ≈ 0.5–1 s.** Shallow optimum, so the exact value is
   not critical. One line of code.
4. **Log the standing wheel speed.** It is a direct health indicator: near zero
   is good, a few rad/s means bias or COM offset, and the 180° flip test
   distinguishes them.
5. **Measure the real BMI270 noise and bias.** Log stationary for a few minutes.
   Those three numbers replace the placeholders and make this whole block
   quantitative rather than indicative.
6. **Consider thermal drift** if we ever run for more than a few minutes.

---

## 6 — Caveats

- **Sensor figures are placeholders.** Accelerometer noise, gyro noise and bias
  are all guesses. §4.2 shows the result is *sensitive* to bias, so this is the
  first thing to replace.
- **Bias modelled as constant.** No random walk, no thermal drift.
- **5 s runs.** The bias-driven wheel speed settles well inside that, but a 20 s
  run should confirm nothing drifts on a longer timescale.
- **Single axis, scalar filter.** Corner balancing needs the reduced-attitude
  MEKF; nothing here transfers directly except the physical insight about
  specific force.
- **No IMU misalignment.** A mounting angle error is a constant tilt offset and
  behaves exactly like gyro bias in §4.2 — worth measuring once the panel is
  assembled.

---

## 7 — Open items

- [ ] BMI270 stationary log → real noise density and bias
- [ ] 20 s run to confirm long-term settling
- [ ] Finer τ sweep between 0.3 and 1.5 s with the measured noise figures
- [ ] Thermal drift test: log bias while the motor runs
- [ ] IMU mounting misalignment, once the panel is assembled

---

## Related

- [[Saturation Envelope Test — Block A]] — actuator authority
- [[Discrete Loop Test — Block B]] — loop rate
- [[Firmware Handoff — Panel Stage]] — startup calibration goes here
- [[Disturbance Estimation & Attitude Representation]] — why $Q_h$ matters, and
  the estimator architecture for the cube
- [[Simscape Panel Model — Build Guide]] — §6.5

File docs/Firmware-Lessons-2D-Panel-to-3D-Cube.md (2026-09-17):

---
tags:
  - space-challenge
  - sofia
  - cubli
  - firmware
  - teensy
  - moteus
  - lessons-learned
---

# Firmware Lessons — 2D Panel to 3D Cube

Everything in [`firmware/panel-bringup/`](../firmware/panel-bringup) works end to end on hardware now — the
2D planar panel balances. This note exists so the 3D cube doesn't re-pay the
cost of finding the same bugs twice. Two classes of content: things that
generalize directly to every future wheel/axis (fix once, remember forever),
and things that don't generalize at all and need deliberate rethinking before
the cube starts (flagged explicitly in §7).

Companion to [`firmware/panel-bringup/Bring-Up-Stages-Implementation-Notes.md`](../firmware/panel-bringup/Bring-Up-Stages-Implementation-Notes.md),
which has the full blow-by-blow. This is the condensed, forward-looking version.

---

## 1. Toolchain and libraries

- **Arduino IDE**, not PlatformIO — each stage is a self-contained sketch
  (a folder containing one `.ino` of the same name).
- **`mjbots/moteus-arduino`**, included as `#include <MoteusTeensy.h>` — the
  Teensy CAN-FD backend of the official moteus Arduino library, built on
  `ACAN_T4` for the Teensy 4.1's onboard CAN3.
- **`SparkFun_BMI270_Arduino_Library`** for the IMU, over SPI (not I2C —
  faster, and frees up the I2C bus).
- CAN-FD bus: 1 Mbps arbitration (`ACAN_T4FD_Settings canSettings(1000000, DataBitRateFactor::x1)`),
  Teensy pins 30/31 (CAN3 — the only CAN-FD-capable bus on the Teensy 4.1).

## 2. The moteus command gotcha that cost the most time

`moteus1.SetPosition(cmd)` — called with **no second argument** — does not
send the whole `Command` struct. It uses a default `Format` that only
transmits `position` and `velocity`. Every other field (`feedforward_torque`,
`kp_scale`, `kd_scale`, `maximum_torque`, `watchdog_timeout`,
`ignore_position_bounds`) defaults to `Resolution::kIgnore` and is silently
dropped **before the CAN frame is built** — set in the local C++ struct,
never transmitted, no error, no warning.

Practical effect: a "torque mode" command built the textbook way (`kp_scale
= kd_scale = 0`, `feedforward_torque = tau`) actually becomes a plain
**velocity-mode hold at 0**, because the moteus never hears about the scale
overrides and falls back to its own onboard `kp_scale=1`/`kd_scale=1`. This
is exactly why "velocity mode works, torque mode does nothing" was our
first real symptom — velocity mode was, unknowingly, the *only* thing ever
actually being sent.

**Fix — build once, reuse every cycle, pass explicitly:**

```cpp
static Moteus::PositionMode::Format kTorqueFormat = []() {
  Moteus::PositionMode::Format f;
  f.feedforward_torque     = Moteus::kFloat;
  f.kp_scale                = Moteus::kFloat;
  f.kd_scale                 = Moteus::kFloat;
  f.maximum_torque           = Moteus::kFloat;
  f.watchdog_timeout         = Moteus::kFloat;
  f.ignore_position_bounds   = Moteus::kFloat;
  return f;
}();
...
moteus1.SetPosition(cmd, &kTorqueFormat);   // the &kTorqueFormat is not optional
```

**This generalizes exactly as-is to every wheel on the cube** — same
`Format`, same fields, one per moteus instance. Easy to forget per-instance
if the cube code isn't structured to share it.

## 3. `ignore_position_bounds` — needed for any continuously-spinning wheel

moteus's defaults assume a bounded joint. `servopos.position_min`/`_max`
get checked on **every transition into Position mode**, and a reaction
wheel — which has no natural travel limit and is expected to accumulate many
rotations — will eventually violate them, faulting with code 39 ("outside
limit"). The servo then sits in Fault mode indefinitely: **it keeps
replying to CAN queries normally** (position/velocity telemetry looks
fine), it just silently stops applying any commanded torque. This looks
exactly like "everything reports healthy but nothing happens" — the same
signature the `Format` bug produces, for a completely different reason.
Set `cmd.ignore_position_bounds = 1.0f` (with the matching `Format`
resolution) on every wheel, always.

**Diagnostic worth keeping around:** read and print `Query::Result::mode`
and `::fault` (registers `0x000`/`0x00f`) in telemetry. We didn't have this
at first and it cost real debugging time — mode `1` = FAULT, and the fault
code tells you exactly why (`39` outside limit, `36` motor never
calibrated via `moteus_tool`, `34`/`40` over/under voltage). Cast both to
`(int)` before printing — `fault` is `int8_t`, which `Serial.print()` can
silently bind to its `print(char)` overload instead of the numeric one.

## 4. The wheel-mounting sign convention — will need re-doing per wheel

The LQR model's convention (`Θ̄θ̈ = Sg·sinθ − u`) requires a positive
commanded wheel torque to produce a *restoring* reaction on the body. There
is no way to know in advance whether a given physical motor/wheel mounting
satisfies that convention or its exact opposite — it depends on which way
the motor happens to be wired and mounted, and calibration doesn't fix it
(mjbots' `moteus_tool --calibrate` only ties phase order to encoder
direction *internally consistently*, it says nothing about which way that
is relative to your airframe).

We found ours was backwards — confirmed empirically, not assumed — via a
**deliberately isolated open-loop test**: hold the panel firmly, fire a
single small fixed torque pulse with no feedback loop involved, and
physically watch which way the panel pushes. Fixed with **one constant**,
applied at the hardware boundary, gains left completely untouched:

```cpp
static const float kWheelSign = -1.0f;
...
cmd.feedforward_torque = kWheelSign * tau;
...
const float wheel_omega = kWheelSign * v.velocity * 2.0f * (float)PI;
```

Both sides (outgoing torque *and* incoming velocity) need the same
constant wherever the code has a taper or a momentum-management term that
depends on `tau` and `wheel_omega` staying mutually consistent — flipping
only one side fixes the panel-reaction direction while breaking that
internal consistency.

**Does not generalize automatically to the cube.** Three (or more) wheels
means three independent physical mountings, and there is no reason to
assume they share a sign — verify each wheel's `kWheelSign` independently,
with the same isolated single-pulse test, before ever combining them in a
closed loop. Assuming symmetry here is exactly the kind of shortcut that
turns into an unexplainable multi-axis runaway that's much harder to
isolate than a single-axis one.

**One firmware rule that made isolating both of the above tractable, worth
keeping as a hard rule going forward:** never flip a sign to compensate for
unexpected behavior without first proving *which* layer is wrong via an
isolated, feedback-free test. `K1`/`K2`/`K3` (or their cube-scale
equivalents) should never be hand-flipped — every sign in the gains traces
back to a `Q`/`R`/plant choice; the mounting/estimator convention is a
separate, physical fact that gets corrected in exactly one place.

## 5. Estimator (Stage 1 complementary filter)

```cpp
const float theta_acc = atan2f(imuData.ax - imuData.ay,
                               imuData.ax + imuData.ay) - kThetaOffset;
```

Works specifically because the IMU sits at 45° to the panel's rotation
axis: `ax - ay ∝ sin(theta)`, `ax + ay ∝ cos(theta)`, the ratio cancels `g`
so calibration scale doesn't matter, and `atan2` stays singularity-free
over the full ±180°. **This exact trick is 2D/45°-mount specific** — it
does not extend to a 3-axis attitude estimate. See §7.

- `kThetaOffset`: mount angle is never exactly the design value; this gets
  measured on the bench (balance by hand at true vertical, read the raw
  angle, that's the offset) and is live-settable over serial rather than
  baked in, specifically so recalibration doesn't cost a reflash.
- `kTau = 1.0` s (not the more intuitive-looking 0.5): the filter's
  error has a U-shaped optimum in `tau` — too short and lever-arm/
  accelerometer noise leaks through, too long and residual gyro bias
  dominates (`error ≈ bias × tau`). Our measured gyro bias was small
  (0.0005–0.0023 rad/s), which pushes the optimum up, not down. Re-measure
  this for the cube's actual IMU/gyro rather than assuming 1.0 s carries
  over — it's a function of the specific sensor's bias, not the mechanism.
- Accelerometer gate at `|a|` within ±15% of 1g before trusting the
  accel-derived angle — rejects the systematic error where wheel reaction
  torque injects tangential acceleration that isn't gravity. Keep this
  loose, not tight: the contamination is roughly perpendicular to gravity
  and barely moves `|a|`, so a tight gate catches little while risking
  rejecting good samples.
- Gyro bias subtraction, applied per-axis before anything else touches the
  raw reading. Small (sub-0.01 rad/s) but real, and free to correct once
  measured.

## 6. Real actuator limits vs. modeled ones

- Real static friction/stiction on this rig needed **≥0.05 N·m** before
  producing any visible wheel motion — confirmed empirically, not
  predicted. `0.01 N·m` (a seemingly-reasonable "deliberately small, safe"
  first test pulse) sat below that threshold and looked exactly like a
  dead command path even with everything else working correctly. Size the
  cube's first open-loop test pulses with real margin above whatever
  stiction turns out to be for its actuators, and don't conclude "broken"
  from a null result at a torque that was never going to move anything.
- **Sanity-check gain magnitude against actuator capability before ever
  arming.** `K_t` and `servo.max_current_A` give a real, computable ceiling
  on deliverable torque (`τ_max ≈ K_t × I_max`). A gain vector where a
  fraction of a degree of tilt alone would already demand more torque than
  that ceiling means the "controller" is actually running open-loop
  bang-bang against noise, not proportional LQR — regardless of how
  correctly the rest of the pipeline is wired. Worth computing this ratio
  explicitly for each cube wheel's actual gains before first power-on, not
  after something looks wrong.
- Reaction-wheel torque and panel push are coupled by Newton's third law
  *the instant current flows*, independent of whether the rotor actually
  overcomes friction and turns. A correction that produces no visible
  wheel motion but *is* physically pushing against your hand is working
  correctly, not silently failing — don't use "does the wheel spin" as the
  only signal when isolating gain terms by hand.

## 7. Staged bring-up — the methodology, not just the specific stages

The concrete stages (`firmware/panel-bringup/Stage0`…`Stage5`) are 2D-specific, but
the *shape* of the progression is exactly what caught both bugs in §2 and
§4 cleanly instead of as an unexplainable tangle, and is worth repeating
for the cube nearly unchanged:

1. **Estimator-only, motor structurally incapable of moving** (not just
   commanded zero — no code path that *can* send nonzero torque). Prove
   the sensor signs and filter before any actuation risk exists.
2. **A single, small, fixed open-loop pulse, held by hand, no feedback
   loop.** The only stage that can isolate the mounting/reaction sign
   convention (§4) without a closed loop's dynamics confounding the
   result.
3. **One gain term at a time**, closed loop, still hand-held. A sign error
   here fights your hand, not gravity — cheap to catch, cheap to recover
   from.
4. **Combined terms, gain ramped from low to full authority manually**
   between runs — a residual sign or scale error shows up as "this feels
   backwards at low gain," not a runaway at full gain.
5. **Full authority, unsupported**, only after all of the above passed.

Safety scaffold that made this survivable and worth carrying forward
unchanged in spirit:
- **Latching trips, never auto-clearing** — tilt limit, wheel-speed limit,
  NaN/non-finite guard. Re-arming is always a deliberate action.
- **NaN guard strictly before any clamp** — a clamp alone lets NaN through
  silently (every comparison against NaN is false).
- **Taper that fades spin-up torque only, never braking** — approaching a
  wheel-speed cap should never remove your only way to *stop*.
- **A halt command independent of arm/disarm** — closing a serial monitor
  does not stop a running microcontroller; something explicit has to.

For the cube specifically: don't jump from "one wheel/axis isolated and
working" straight to "three wheels closed loop simultaneously." Isolate
each wheel's sign convention and each axis's estimator independently
first, exactly as this progression did for one.

## 8. LQR retuning workflow (unchanged in principle for 3D)

Two different activities, easy to conflate:

- **Re-deriving `K` from a better plant** (do this first, always): measure
  the real `Theta`/inertia from a free-swing period test on the *built*
  hardware (`Θ̂ = Sg·T²/4π²` for the 2D case), update the plant model,
  re-run `lqr(A, B, Q, R)`. Not tuning — just a more accurate derivation.
- **Adjusting behavior via the Bryson weights** (`theta_max`, `rate_max`,
  `omega_des`, `rho_lqr`), never by hand-editing `K` values directly.
  `rho_lqr` is the one master speed-vs-effort knob; the sweep in
  `cubli_lqr_design.m` CHECK 9 already does this systematically rather
  than by guessing one value at a time.

For the cube: the plant matrices themselves change completely (3D rigid-body
dynamics, not the 1D `Θ̄θ̈ = Sg sinθ − u` reduction) — see
[`../docs/dynamics/3D-Cubli-Lagrangian-Derivation.md`](../docs/dynamics/3D-Cubli-Lagrangian-Derivation.md).
The *workflow* (measure → derive → simulate → validate on hardware →
re-measure) carries over; none of the actual numbers do.

## 9. Verify published numbers against the code that produced them

The closed-loop pole figures quoted in two different docs for this project
(`"about -15, -9, -6"` and, separately, `"-9.72 ± 0.76j, -5.05"`) were both
wrong — neither matched `eig(A - B*K)` run against the actual deployed `K`
and the measured-mode plant, which gives **≈ -12.5, -9.7, -6.3 rad/s, all
real**. `K` itself was correct; only the documented poles were stale/mis-
transcribed. Small thing, but a reminder: derived numbers drift from the
code that produces them, especially across multiple doc revisions. Worth
independently re-deriving anything load-bearing (pole locations, margins,
predicted envelopes) from the actual current code before trusting a number
quoted in prose, rather than propagating it forward another time.

## 10. What genuinely does NOT carry over to 3D — explicit list

- **The 45°-atan2 estimator trick (§5)** is mechanically specific to a
  single-axis panel with the IMU at 45° to the pivot. The cube needs a
  real attitude estimator — [`Panel Controller Workflow.md`](../docs/simulation/Panel-Controller-Workflow.md)
  already documents the intended upgrade path (complementary filter →
  scalar Kalman filter → MEKF, MEKF specifically deferred *until* the cube
  stage). See [`../docs/dynamics/Quaternions-Complete-Guide.md`](../docs/dynamics/Quaternions-Complete-Guide.md)
  for the representation.
- **One wheel, one `kWheelSign`, one set of trip thresholds** → three (or
  more) independent wheels, independent CAN IDs, independent sign
  verification per wheel (§4), and a 3D-appropriate trip condition (an
  attitude-error norm or per-axis limits — not yet decided, worth deciding
  deliberately rather than defaulting to "just check each Euler angle
  separately," which reintroduces gimbal-lock-shaped problems the
  quaternion representation exists to avoid).
- **The gains themselves** — `K1`/`K2`/`K3` for the panel are meaningless
  for the cube; full re-derivation per §8, from 3D dynamics per §7 of the
  Lagrangian derivation doc.
- **`kMaxTilt` as a single scalar** — was tied directly to the 2D Build
  Guide's recovery-envelope prediction; the cube's equivalent envelope
  will come from the 3D simulation work, not from picking a number that
  feels similar.

## Related

- [`firmware/panel-bringup/README.md`](../firmware/panel-bringup/README.md) — the 2D firmware itself
- [`firmware/panel-bringup/Bring-Up-Stages-Implementation-Notes.md`](../firmware/panel-bringup/Bring-Up-Stages-Implementation-Notes.md) — full per-stage code walkthrough
- [`firmware/panel-bringup/Arduino-Bring-Up-Plan-Sections-2b-2d.md`](../firmware/panel-bringup/Arduino-Bring-Up-Plan-Sections-2b-2d.md) — the original procedure
- [`../docs/simulation/Panel-Controller-Workflow.md`](../docs/simulation/Panel-Controller-Workflow.md) — plant/LQR/retuning pipeline, MEKF upgrade path
- [`../docs/dynamics/1D-Jig-to-3D-Cube-Strategy.md`](../docs/dynamics/1D-Jig-to-3D-Cube-Strategy.md) — the staged 2D→3D plan this note feeds into
- [`../docs/dynamics/3D-Cubli-Lagrangian-Derivation.md`](../docs/dynamics/3D-Cubli-Lagrangian-Derivation.md) — the 3D dynamics the cube's `A`/`B` will come from

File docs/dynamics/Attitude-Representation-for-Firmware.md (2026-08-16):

# Attitude representation for the Teensy firmware

**Use `gam`, the gravity direction in body coordinates. Not Euler angles, not
a quaternion.** This note is the reasoning, because the choice is not a style
preference - it decides whether the loop works.

## 1. What the controller actually needs

The design plant is  `Tb*omdot = Sg*P*phi - u`,  `P = I - gB*gB'`.

Only the component of attitude error PERPENDICULAR to `gB` appears. The
parallel component - yaw about the vertical - is:

- **unobservable.** One vector measurement fixes 2 DoF of attitude, not 3. An
  accelerometer tells you which way is down, never which way you are facing.
- **uncontrollable.** `rank(ctrb) = 8 of 9`, because `gB'*(Theta*om + Is*rho)`
  is conserved: the wheels are internal and gravity has no moment about the
  vertical.

Yaw is not merely unnecessary. Any representation carrying it is carrying a
state that cannot be measured and cannot be driven, and that state will find a
way to contaminate the two that matter.

## 2. What `gam` is

A unit 3-vector: the direction of gravity in the CUBE BODY frame. `gam == gB`
is balanced. Three numbers, one norm constraint, **2 DoF - exactly the
observable and controllable subspace, nothing more.**

It is also what the sensor gives: `gam = normalize(-a_cal)`.

Kinematics is one line, `gamdot = -om x gam`, and the control input is one
cross product, `phi = -gB x gam`.

`phi` is perpendicular to `gB` **by construction** - a cross product with `gB`
always is. Yaw therefore cannot leak into the tilt channel. Not approximately,
not to first order: exactly, at any attitude. Verified: `P*phi - phi = 6.0e-18`
and a 30 deg pure-yaw rotation moves `gam` by `1.6e-16`. The nonlinear gravity
torque `m*g*(r_c x gam)` matches `Sg*phi` to `9.9e-17 N m`.

## 3. Why Euler angles fail - three MEASURED failures

**Gimbal lock.** The first Simscape model produced `q_y` spikes to +/-20000
deg. A rigid body cannot do that; the parameterisation went singular. On
hardware that is a divide-by-near-zero mid-recovery.

**Euler angles are not the reduced attitude.** Even far from lock the triple
is not a rotation vector, and `P` removes yaw from it only to FIRST ORDER. Yaw
here is not small: `gB'*Theta*gB = 0.00538 kg m^2` makes the cube **4.5x
lighter in yaw than in tilt**, so wheel momentum along `gB` spins the body at
0.090 rad/s per rad/s of `rho.gB`. Released from 3.6 deg, yaw reaches **23.6
deg within 0.3 s** - momentum-conserving, entirely physical. Feeding the Euler
triple cost **19.5 % of the recovery angle** and the loop diverged.

**Euler rates are not body rates.** `[qd1 qd2 qd3]` equals `omega` only at
`q = 0`; over the trajectory it is **up to 73 % wrong**. Correcting both took
the Simscape model from 3.33 to 4.14 deg, matching the nonlinear simulator to
**0.35 %**.

All three are the same mistake: a signal correct at the equilibrium treated as
correct everywhere.

## 4. Why not a quaternion / MEKF

A quaternion is 4 numbers with a norm constraint and carries yaw EXPLICITLY.
With one vector measurement that direction is unobservable, so a naive MEKF's
covariance grows without bound there unless constrained by hand.

Measured, not theoretical: in the complementary filter the gyro-bias component
along gravity is likewise unobservable. True value 0.149 deg/s, estimator
recovered **exactly 0.000**, while both perpendicular components converged to
truth. Correct behaviour - nothing observes it - and the reduced-attitude form
cannot even represent the problem.

A quaternion MEKF is the right structure when you need large-attitude tracking
against a full reference: **stage 3 jump-up, and corner-to-corner transitions
where `gB` moves 67-107 deg.** Not for corner balance, where tilt stays under
15 deg. A magnetometer would make yaw observable and buy nothing, because yaw
is still uncontrollable.

## 5. The C++ implementation

```cpp
// per corner, from cubli_gains: 3 + 27 floats; 8 corners = 240 total
const float gB[3];              // gravity direction at balance, BODY axes
const float Kp[3][9];           // rows = wheel X,Y,Z; cols = [phi om rho]

// estimator state, persistent
float ghat[3] = { gB[0], gB[1], gB[2] };
float bhat[3] = { 0, 0, 0 };

// ---- once per 400 Hz cycle ------------------------------------------
// 1. sensors, calibrated and already rotated into BODY axes by R_IB
float a[3], w[3], rho[3];       // m/s^2, rad/s, rad/s

// 2. accelerometer -> gravity direction
float ga[3] = normalize(neg(a));

// 3. reduced-attitude complementary filter,  kP = 4, kI = 0.5
float e[3]  = cross(ghat, ga);
float wc[3] = sub(w, bhat);
ghat = add(ghat, scale(add(neg(cross(wc, ghat)), scale(cross(e, ghat), kP)), dt));
normalize(ghat);
bhat = add(bhat, scale(e, kI*dt));       // PLUS. minus converges to 5x the bias
float om[3] = sub(w, bhat);

// 4. the entire attitude computation: one cross product
float phi[3] = neg(cross(gB, ghat));

// 5. LQR, feedforward, limits
float x[9] = { phi[0],phi[1],phi[2], om[0],om[1],om[2], rho[0],rho[1],rho[2] };
float u[3];
for (int i=0;i<3;i++) {
    u[i] = 0.0f;
    for (int j=0;j<9;j++) u[i] -= Kp[i][j]*x[j];
    u[i] += tau_cw*tanhf(rho[i]/eps_ff) + b_w*rho[i];    // friction FF
    u[i]  = clampf(u[i], -tau_max, tau_max);
    if ((rho[i] >=  omega_cap && u[i] > 0.0f) ||
        (rho[i] <= -omega_cap && u[i] < 0.0f)) u[i] = 0.0f;
}
```

### Cost

Three cross products, one 3x9 matvec, one reciprocal square root, three
`tanhf`. About 60 multiply-adds. **No `atan2`, no `sin`/`cos`, no quaternion
product, no matrix exponential, no sequence convention to get wrong.** `float`
is sufficient - everything is a unit vector or an O(100) rate. On a 600 MHz
Teensy 4.1 the 2.5 ms budget goes to CAN, not to this.

### The contract

- State order `[phi(3); om(3); rho(3)]`, body axes X, Y, Z, in THAT order.
- **Do not port the Simscape Mux permutation `[1 4 2 5 3 6 7 8 9]`.** It is an
  artefact of how the model happens to be wired. Firmware builds the vector
  directly in design order.
- `phi` and `om` are in the CUBE BODY frame. Rotate the IMU output by `R_IB`
  first, and verify `R_IB` with the six-face test - never from the datasheet
  drawing.
- `rho[k] > 0` means rotation about `+body axis k`. Verify per wheel on the
  bench.

### One numerical caution

`e = cross(ghat, ga)` has magnitude `sin(error)`: well behaved under 90 deg,
but zero again at 180 deg. If the cube is picked up and inverted, `ghat` can
lock onto the antipode. Add a reset - if `dot(ghat, ga) < 0` for N consecutive
cycles, set `ghat = ga` and zero `bhat`. Disarm above ~15 deg of tilt: past
recovery range the torque is only noise and heat.
"},"

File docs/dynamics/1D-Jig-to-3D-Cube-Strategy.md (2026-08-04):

---
tags: [space-challenge, sofia, cubli, prototyping, controls, validation, strategy]
---

# The 1D Jig → 3D Cube Strategy — what each stage validates and what transfers

The single most important strategic decision in the build: **we do not build the 3D cube first.** We build a 1-dimensional jig, prove the entire control loop on it, then replicate that proven loop into 3D. This note explains exactly *why*, exactly *what the jig validates*, and exactly *what transfers to the cube and how*.

The core claim: **these are not three separate prototypes. They are one system revealed in increasing dimension.** Each stage is the next stage minus a dimension, and nearly everything — theory, code, estimator, tuning method — carries forward untouched.

Companion notes: [[Sizing Memo]], [[Structural Constraints]], [[3D Cubli Lagrangian Derivation]] (§8 is the mathematical basis for why 1D→3D works), [[Revised Schedule - Provided Hardware]].

---

## 1. The three stages and the ONE risk each retires

A prototype earns its place only if it lets us **fail cheaply now instead of expensively later.** By that test, exactly three stages, no more:

| Stage | Physical form | The one question it answers |
|---|---|---|
| **Simscape model** | virtual | Is the control *theory* correct at all? |
| **1D jig** | 1 motor, 1 wheel, balances on an **edge** | Does the whole control *loop* work on *real hardware*? |
| **3D cube** | 3 motors, 3 wheels, balances on a **corner** | Do the genuinely-3D problems (coupling, allocation, frames) work? |

The logic: the Simscape model kills all *theory* risk with zero hardware. The jig kills all *component and single-loop* risk with one motor. By the time we build the cube, the only risks left are the ones that are *inherently* three-dimensional — everything else is already dead.

---

## 2. Why the 1D jig is the highest-leverage object in the whole project

This is the stage people skip to "save time," and it is the single most expensive mistake available to us. Here is the exact reasoning.

### 2.1 What the jig physically is

An arm that pivots on a single horizontal axis (an **edge**, not a corner), with **one** motor driving **one** reaction wheel whose spin axis is parallel to the pivot. It balances like a broomstick on a hand, but in one plane only. That's it. A printed arm, one motor, one wheel, one encoder, one IMU, the real driver, the real compute.

### 2.2 The physics is IDENTICAL to the cube, minus two axes

This is the crucial fact and the mathematical justification is already in our derivation. From [[3D Cubli Lagrangian Derivation]] §8: **the 1D edge-balancing equation is the full 3D equation with the cross-product (gyroscopic) terms set to zero.**

$$\underbrace{(\hat\Theta_e - I_w)\,\ddot\theta = mg\ell\sin\theta - u}_{\text{1D jig}} \qquad\Longleftarrow\qquad \underbrace{\bar\Theta\,\dot{\boldsymbol\omega} = -\boldsymbol\omega\times(\bar\Theta\boldsymbol\omega + A\boldsymbol h) + m\,\boldsymbol c\times\boldsymbol g_B - A\boldsymbol u}_{\text{3D cube}}$$

The 1D case is not an *analogy* for the cube. It is *literally the same system of equations*, evaluated on a single axis where the $\boldsymbol\omega\times(\cdot)$ coupling vanishes. Same instability ($mg\ell$ gravity term), same actuation ($u$), same wheel-momentum bookkeeping ($\dot h = u$). A controller that balances the jig is solving the identical mathematical problem the cube solves, in one axis.

### 2.3 What the jig VALIDATES — the exhaustive list

Everything below is **1-dimensional physics**, so it can be tested and fixed with a single motor, but every item is a risk that would otherwise surface — coupled with two other axes — in the 3D cube during week 3, when there is no schedule slack:

**Hardware/component risks:**
1. **Torque-mode driver actually works.** Our entire model assumes the driver takes a *torque* command ($\dot h = u$). If it's secretly speed-mode or the FOC tuning is off, *nothing* works. The jig proves this with one motor. (This is the open EnduroSat question — the jig is where it gets answered definitively.)
2. **Encoder mount survives at speed.** An outrunner encoder that slips or loses counts at 8000 rpm is a mechanical problem you want to find on a jig, not inside an assembled cube.
3. **Real control loop rate and jitter.** We computed a ~200 Hz minimum; the jig *measures* what the hardware actually delivers, under real sensor-read and motor-write load.
4. **Sensor noise on the real IMU.** The estimator was designed against modeled noise; the jig exposes it to the actual gyro/accel noise, vibration, and bias.

**Control/estimation risks:**
5. **The estimator works on real signals.** Complementary filter or Kalman — does it reconstruct the tilt angle from real, noisy, vibrating sensor data? 1D is the honest first test.
6. **LQR gains from the model transfer to hardware.** We design gains in sim; the jig is the first proof that a model-designed controller stabilizes *real* hardware. If it doesn't, the model is wrong and we fix it here, cheaply.
7. **Parameter identification method works.** Free-swing period → inertia, spin-down → friction (see [[Deriving Dynamics from CAD]] §4). The jig is where we practice and validate the ID procedure that we'll later apply to the cube.

**The one number jump-up depends on:**
8. **Brake efficiency $\eta_{brake}$.** Our jump-up feasibility (margins ×1.3+) assumes $\eta_{brake} \approx 0.65$ — an *unmeasured estimate*. The jig is where we spin a wheel up, brake it, and *measure* how much momentum actually transfers. Until this number is measured, jump-up is a hypothesis. The jig turns it into a fact.

### 2.4 Why skipping it is the expensive path

Skip the jig, build the full cube, and when it won't balance the cause could be **any** of: bad gains, wrong encoder counts, slow loop, estimator noise, a coordinate-frame sign error, driver not in torque mode, mechanical wheel imbalance, cross-axis coupling — **across three coupled axes simultaneously.** Isolating one failure among eight candidates times three axes is a multi-day debugging nightmare, and it lands in week 3.

The jig collapses that search space. It isolates risks 1–8 in one plane with one of everything, where the physics is trivial to reason about. **The jig does not add a build — it removes days of week-3 debugging.** That is why it is faster, not slower, under time pressure.

---

## 3. What EXACTLY transfers from jig to cube, and how

The scalability question decided whether this strategy is efficient. Answer: nearly everything transfers, because the jig and cube share structure by design. Item by item:

### 3.1 The equations of motion — transfer: STRUCTURAL, exact
The jig's equation *is* the cube's equation restricted to one axis (§2.2). Going 1D→3D you don't rewrite the dynamics — you **re-enable the terms you had zeroed**: the gyroscopic coupling $\boldsymbol\omega\times(\cdot)$ and the two extra axes. The gravity term, the actuation term, the wheel dynamics are unchanged in form. In the code, the 1D plant model is the 3D plant model with `A = a_single_axis` instead of `A = eye(3)`.

### 3.2 The control law — transfer: IDENTICAL structure, re-solved
LQR is LQR. On the jig you solve `K = lqr(A,B,Q,R)` for a 3-state model; on the cube you solve the *same call* for a 9-state model. The **design method is byte-for-byte identical** — same cost-function philosophy (penalize tilt, rate, and wheel momentum), same Riccati solve, same tuning intuition for Q and R. What changes is only the matrix dimensions. Every hour spent understanding *why* a gain choice behaves a certain way on the jig is directly reusable on the cube.

### 3.3 The firmware — transfer: ~80% reused verbatim
This is the big one. The firmware architecture is **identical**:
```
read sensors → estimate state → compute u = -K*x → command torque → repeat
```
- **Sensor drivers** (IMU read, encoder read): identical code, just instantiated 3× on the cube.
- **Estimator**: same filter, extended from scalar angle to attitude — same structure, more states.
- **Control loop timing, torque command path, safety cutoffs**: identical.
- **What's genuinely new on the cube**: reading 3 encoders instead of 1, the 3-axis attitude estimator (quaternion instead of scalar angle), and the control *allocation* (mapping 3 desired torques to 3 wheels — trivial for orthogonal wheels, $A = I$). That's it. The scaffolding — the ~80% that is tedious to get right and easy to get subtly wrong — is written and debugged *once*, on the jig.

### 3.4 The estimator — transfer: same structure, +2 axes
Jig: reconstruct scalar tilt $\theta$ from gyro + accelerometer. Cube: reconstruct attitude (quaternion / $\boldsymbol g_B$) from gyro + accelerometer. **Same sensor-fusion principle** (integrate gyro, correct drift with the gravity vector from the accelerometer), same tuning approach, extended from 1 angle to a reduced-attitude vector. The 1D version is the honest debugging ground for the fusion logic before 3D bookkeeping is added.

### 3.5 The parameter-ID procedure — transfer: identical method
Free-swing period → inertia; spin-down → friction; spin-up → wheel inertia and torque-mode verification (see [[Deriving Dynamics from CAD]] §4). **The exact same measurements**, done on the jig first (fast, one axis) then on the assembled cube (three axes). You learn the procedure where it's cheap.

### 3.6 The Simscape model — transfer: 1D model → 3D model, same pattern
The virtual side scales the same way: `cubli_1d.slx` (one body, one wheel, revolute pivot) → `cubli_3d.slx` (one body, three wheels, spherical pivot). Same parameter file (`cubli_params.m`), same LQR-from-linearization workflow, same validation checklist. The 1D Simscape model validates against the jig; the 3D model validates against the cube. Structure identical, dimension increased.

### 3.7 Summary table — the transfer map

| Element | Jig → Cube | What's actually new |
|---|---|---|
| Equations of motion | structural, exact | re-enable gyroscopic + 2 axes |
| LQR control law | identical method | 3→9 states, same solve |
| Firmware | ~80% verbatim | 3× sensors, attitude estimator, allocation |
| Estimator | same fusion principle | scalar angle → reduced attitude |
| Parameter ID | identical procedure | done 3× instead of 1× |
| Simscape model | same workflow | 1 wheel → 3 wheels, revolute → spherical |

**Nothing is thrown away.** The jig is not a throwaway prototype — it is the cube's control system, born and debugged in one dimension.

---

## 4. What does NOT transfer (the genuinely-3D problems)

Being honest about the boundary. These are the risks the jig *cannot* retire, and therefore the *only* things that should still be unknown when we start the cube:

1. **Gyroscopic cross-coupling.** The $\boldsymbol\omega\times(\cdot)$ terms that are zero in 1D. At low balancing speeds these are small, but they're real and only appear in 3D.
2. **Control allocation across 3 wheels.** Trivial for orthogonal wheels (identity map), but it's new code.
3. **Full attitude estimation.** Quaternion/reduced-attitude fusion vs. scalar angle — more bookkeeping, the double-cover and yaw-unobservability subtleties from [[Quaternions Complete Guide]].
4. **Corner pivot vs. edge pivot.** Geometry, the hardened tip, 3-axis symmetry of the mechanical build.

That's the whole list. Because the jig retired everything else, the cube's bring-up is *only* these four — a tractable problem, not an eight-headed one.

---

## 5. The bottom line for scheduling

- The jig is a **parallel week-1 workstream** — with ~15 people it costs nothing on the critical path and buys down the most risk of any single activity.
- It is the first place the **open driver-mode question** and the **unmeasured brake efficiency** get definitively answered — both of which gate later decisions.
- If (and only if) the team were too small to parallelize it, the jig would be the first cut — but almost everything else should be cut before it, because it is the highest-leverage risk-reducer in the plan.

**One system, three dimensions of it. Build the 1D truth first; the 3D cube is that truth replicated three times.**

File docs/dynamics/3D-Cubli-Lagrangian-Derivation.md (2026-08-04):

---
tags: [space-challenge, sofia, cubli, dynamics, derivation]
---

# Cubli 3D — Full Lagrangian Derivation of the Equations of Motion

Target system: the **most advanced Cubli realistically buildable in Sofia** — the full ETH-style 3D Cubli. A rigid cube pivoting on one **corner**, with **three reaction wheels** mounted on three mutually orthogonal faces, each driven by a BLDC motor. Capable of corner balancing and (stretch) jump-up. This is the configuration of Gajamohan et al. (ECC 2013) and Muehlebach & D'Andrea (TCST 2016); the derivation below follows their structure, with the quaternion/vector formalism of Ribas Martins & da Silva (arXiv:2009.14625) where it's cleaner.

Everything is derived from scratch so it can be checked line by line, then specialized to the 1D edge case as a sanity check at the end.

---

## 1. System definition and assumptions

**Bodies.** Four rigid bodies:
- the **structure** $\mathcal{S}$: cube housing, motors' stators, electronics, batteries — everything that does *not* spin with the wheels;
- three **reaction wheels** $\mathcal{W}_1, \mathcal{W}_2, \mathcal{W}_3$, each spinning about a body-fixed axis.

**Assumptions.**
1. The pivot corner $O$ is a fixed, frictionless point contact — the cube rotates about $O$ but does not translate or slip. (Holonomic constraint: 3 translational DOF removed.)
2. Each wheel is axisymmetric about its spin axis, so its inertia tensor is invariant under its own spin. This is *the* key simplification: the total system inertia about $O$ is constant in the body frame.
3. Wheel spin axes $\{\boldsymbol a_1, \boldsymbol a_2, \boldsymbol a_3\}$ are mutually orthogonal unit vectors, fixed in the body frame, aligned with the cube's face normals.
4. Motors apply torques $u_i$ about $\boldsymbol a_i$ between structure and wheel $i$ (action–reaction pair).
5. Aerodynamic drag neglected; wheel bearing friction optionally modeled later as viscous ($-b_w\dot\varphi_i$).

**Degrees of freedom.** After the pivot constraint: 3 (attitude of the cube) + 3 (wheel spin angles) = **6 DOF**. Configuration space $SO(3) \times \mathbb{T}^3$ — this non-Euclidean configuration space is why plain Lagrange equations in coordinates are awkward and we will use the Euler–Poincaré form for the rotational part (§7).

---
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

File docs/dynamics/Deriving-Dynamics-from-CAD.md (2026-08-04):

---
tags: [space-challenge, sofia, cubli, cad, dynamics, controls, interface]
---

# Deriving the Dynamics from CAD — the CAD↔Controls interface

How the structural team's CAD becomes the numbers in the equations of motion. This is an **interface document**: it defines exactly what Structure delivers, in what frame, with what conventions, and how Controls validates it against reality.

Companion file: `cubli_params.m` — the single source of truth, with the contract encoded and sanity checks that fire on convention errors.
Model reference: [[3D Cubli Lagrangian Derivation]] §2, §4.3, §7.

---

## 0. What the model actually needs

From the derivation, the EOM need exactly these quantities — nothing more:
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

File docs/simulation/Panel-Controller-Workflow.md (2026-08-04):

---
tags: [space-challenge, sofia, cubli, controls, simscape, workflow, panel]
---

# Panel Controller Workflow — plant, LQR, Simscape, retuning

The design pipeline for the Stage 1 planar panel controller: from equations to deployable gains, with three retunes as the plant model gets more accurate.
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

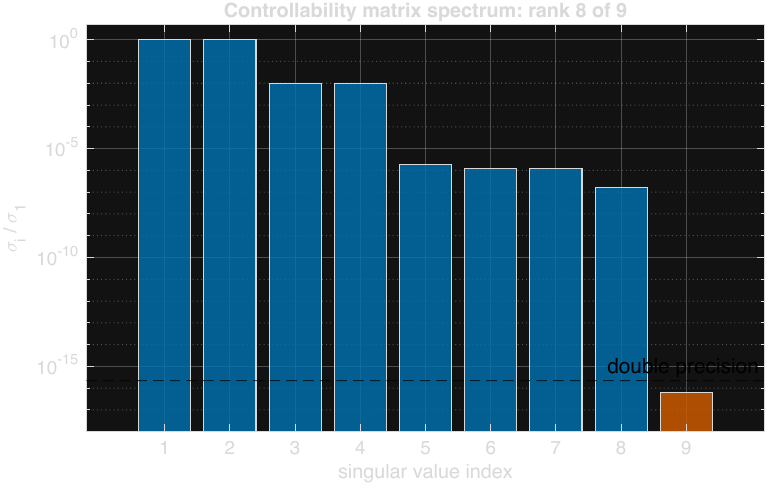
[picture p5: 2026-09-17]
figures/simulation/png/ctrb_spectrum.png

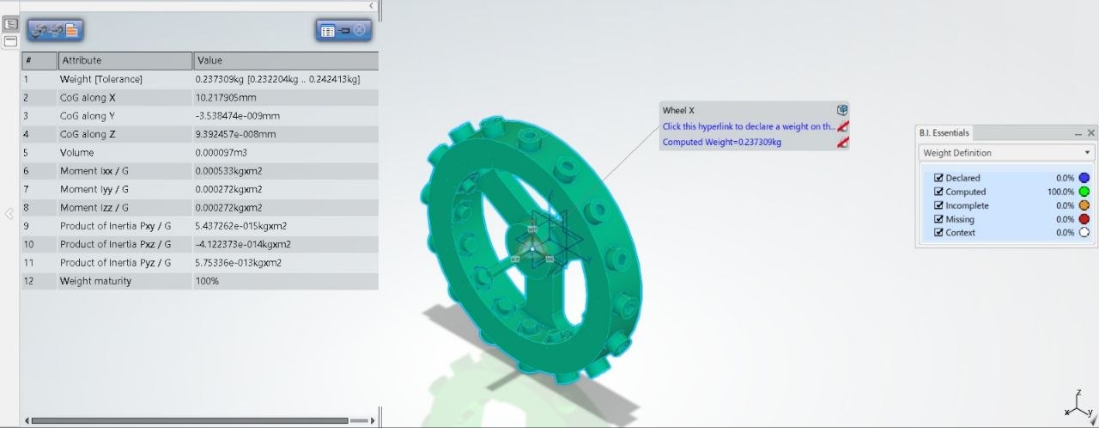
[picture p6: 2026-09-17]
figures/cad/wheel_data.jpg

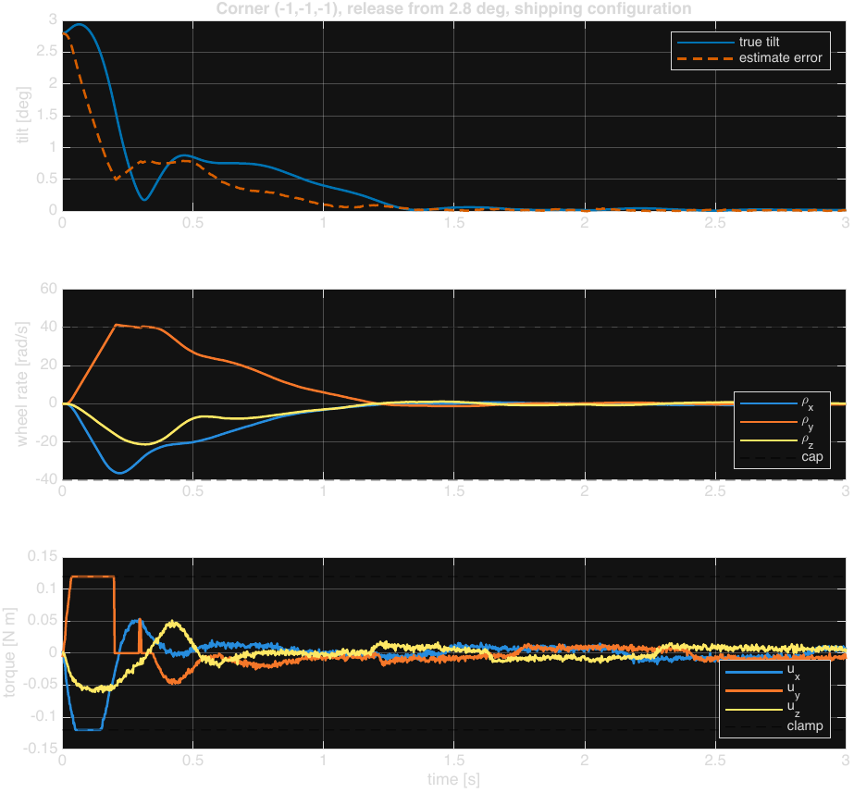
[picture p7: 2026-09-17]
figures/simulation/png/cube_recovery.png

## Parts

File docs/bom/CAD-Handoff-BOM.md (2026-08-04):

---
tags: [space-challenge, sofia, cubli, cad, handoff, bom]
---

# CAD Handoff — fill in when BOM arrives

Purpose: the moment the BOM lands, this note turns into CAD's starting brief in minutes. Numbers are **blank slots** to fill after the sizing script runs on real inputs and the team picks the envelope. Everything that *doesn't* depend on a number is already here and final.

Sizing tool: `cubli_sizing.m` in `Documents/MATLAB/Space Challenge 2026` (run it with real inputs → read the sweep → the team chooses).
Companion: [[Deriving Dynamics from CAD]] (export format), [[Structural Constraints]], [[Week 1 Plan]].

---

## STEP 1 — three questions that gate scope (answer first, from BOM/mentor)

CAD is technically unblocked before these, but the *jump-up scope* and *component list* depend on them:

- [ ] **Driver control mode** — torque/current (FOC) or throttle ESC? → decides if the control architecture stands or needs re-derivation.
- [ ] **Encoders present in BOM?** → if not, flag immediately (sensorless can't balance at zero speed).
- [ ] **Battery 4S or 6S?** → sets wheel momentum (±50%), which sets jump-up margin.

---

## STEP 2 — lock the envelope (fill after team decides)

Run `cubli_sizing.m` with real BOM numbers, read the sweep, let the team choose. Then fill:

- **Cube side length:** ________ mm   *(recommendation going in: ~120 mm — smaller improves hold/catch/jump together; floor ~110 mm set by wheel radius room)*
- **Max total mass:** ________ kg   *(target ~0.9 kg)*
- **Recovery angle:** ________ deg   *(going in: 10°)*
- **Max (mass × COM) budget:** ________ kg·m   *(from sizing script §2)*
- **Jump-up in scope?** yes / no   *(depends on jump margin ≥ ×1.3 in the sweep)*

---

## STEP 3 — wheel targets (fill after envelope)

- **Wheel outer radius:** ________ mm   *(as large as the face allows — bigger = mass-efficient momentum)*
- **Wheel mass each:** ________ g   *(≈55–80 g; ring/rim-weighted)*
- **Hub requirement:** must allow **adding rim mass later** (start light for the pass, bolt on rings if jump-up margin needs it).

---

## STEP 4 — CAD rules (final, number-independent — apply regardless)

These don't wait on the BOM. Non-negotiable:

1. **Sensors in CAD from v0.** Every rigidly-attached mass — IMU, encoder + magnet/PCB, driver board, compute, wiring — goes in as a mass-and-volume placeholder from the *first* pass, not just the structural shell. Leaving them out = wrong COM and wrong inertia tensor = gains tuned against a model that doesn't match the built object.

2. **Jig first, cube second.** Design the 1D jig (one arm, one motor, one wheel, edge pivot) *before* the cube. It's printable in a day and unblocks the whole week-1 validation.

3. **Jig simplification:** keep **compute and power off-board** (bench supply + tethered Teensy) so the jig stays light. But **IMU and encoder positions must be deliberate and in-model** — their placement affects the physics being validated.

4. **Frame convention** (identical in CAD, Simscape, firmware): origin at the **pivot corner**, axes along the three cube edges from that corner, right-handed, **SI units** (metres/kg — CAD defaults to mm/g, a 10⁻⁹ tensor error waiting to happen).

5. **Print-density calibration** early: print a coupon of known volume, weigh it, back out effective density, enter as custom material. Removes the biggest single CAD mass error. Weigh every bought part (motor, battery, boards) and use mass-override.

6. **Wheels excluded from the structure tensor.** Export **two** mass-property sets: structure-with-wheels-suppressed, and one wheel alone. Motor stators → structure; rotors → wheel. (Why: the model treats wheels as separate spinning bodies; a single lumped inertia destroys the rotor-coupling term.)

7. **Fabrication must-haves in the design:** hardened pivot tip (steel insert, not printed plastic) + friction pad; heat-set inserts for fasteners; wheel guards; designed-in COM-trim shim provision; battery mounted **dead-centre on the body diagonal** (dominates COM).

---

## STEP 5 — the deliverable CAD hands back to controls

Fill this table per revision and hand to controls (feeds `cubli_params.m`). See [[Deriving Dynamics from CAD]] §7 for full detail.

| Field | Symbol | Units | Frame/point |
|---|---|---|---|
| Structure mass (wheels excluded) | m_S | kg | — |
| Structure COM | — | m | body frame, origin at pivot |
| Structure inertia tensor | Θ_S | kg·m² | **about pivot corner**, body frame |
| Wheel mass (one) | m_w | kg | — |
| Wheel inertia, spin axis | I_w | kg·m² | about wheel COM |
| Wheel inertia, transverse | J_w | kg·m² | about wheel COM |
| Wheel COM positions (×3) | r_i | m | body frame |
| Cube edge length | a | m | — |
| Convention statement | — | — | "off-diagonals are −∫xy dm" ✔ |

**Cadence:** v0 estimate ASAP (placeholder masses fine — controls just needs *a* number to start the model), real measured masses after first print/assembly.

---

## Reference: the trade-off sweep (verified MN4006, 6S, wheel r58/60g)

Why the envelope is what it is — CAD should see the reasoning, not just the number:

```
 side  mass   | hold@10 | catch@10 | jump f->e | tc   | loop
 (mm)  (g)    | cont    | peak     | margin    | ms   | Hz
 --------------------------------------------------------------
 110   700    |  15.0   |  59.9    | x2.84 OK  | 109  | 229
 110   900    |  11.6   |  42.3    | x2.22 OK  | 109  | 229
 120   700    |  13.8   |  52.4    | x2.50 OK  | 114  | 220
 120   900    |  10.7   |  38.1    | x1.95 OK  | 114  | 220
 130   900    |   9.8   |  34.7    | x1.73 OK  | 118  | 211
 150   900    |   8.5   |  29.6    | x1.40 OK  | 127  | 197
 150   1100   |   7.0   |  23.8    | x1.15 WEAK| 127  | 197
```

Pattern: **smaller improves hold, catch AND jump at once** (shorter lever arm). Only cost is a marginally faster loop the Teensy ignores. Counter-pressure: smaller face → less room for large wheels. Sweet spot ~110–120 mm.
```
```

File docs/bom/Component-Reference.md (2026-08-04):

---
tags: [space-challenge, sofia, cubli, components, hardware, reference, bom]
---

# Component Reference — full specs

One page per subsystem, every BOM item. **Verified** = manufacturer datasheet or docs. **Estimate** = flagged, needs measuring or confirming.

Motor has its own note: [[Motor - TMotor Antigravity 4006]]. Architecture: [[System Integration - Full Cube]].

---

## 1. Actuation

### 1.1 mjbots moteus-n1 — motor driver ×3

| Parameter | Value |
|---|---|
| Topology | 3-phase brushless **FOC** |
| Input voltage | **10–54 V** (≤12S) — 6S at 25.2 V full is comfortably inside |
| Phase current | **9 A uncooled**, 26 A cooled, **100 A peak** |
| Peak electrical power | 2 kW @ 36 V |
| **Control rate** | **15–30 kHz** |
| PWM switching | 15–60 kHz |
| CPU | STM32G4 |
| Comms | **5 Mbps CAN-FD**, ±58 V bus fault protection |
| Current sense noise | ~30 mA |
| Dimensions | **46 × 46 × 8 mm** |
| Mass | **14.6 g** |
| Temperature | −40 to +85 °C |
| Peripheral power out | 3.3 V and 5 V, **100 mA each** total across aux connectors |
| Firmware | open source, Apache 2.0 |
| Included | 1× XT30 connector, 1× JST-PH3 housing + crimps, 1× ¼″ diametric magnet |

**Ports:** AUX2 = JST **GH-7** (this is where the MA600 goes). Power = XT30. CAN = JST PH3, daisy-chainable.

**Headroom check:** 9 A uncooled × $K_t$ 0.02513 = **0.226 N·m continuous from the driver**, versus the motor's thermal limit near 0.12 N·m. **The motor binds, not the driver** — comfortable.

> ⚠️ **The n1 has an integrated on-axis absolute encoder** (AS5047P-class) and ships with a magnet for it. It only works if the board sits directly at the motor shaft end. On our outrunners that's awkward — which is exactly why the BOM includes MA600 breakouts. See §2.1.

Thermal: improvable with a 5 V fan or heat spreader if boards run hot.

### 1.2 TowerPro MG92B — servo ×1–3

| Parameter | Value |
|---|---|
| Type | metal-gear micro servo |
| Torque | ~3.0 kg·cm @ 4.8 V, ~3.5 kg·cm @ 6 V |
| **Speed** | **~0.08 s / 60° @ 4.8 V**, ~0.07 s @ 6 V |
| Voltage | 4.8–6 V |
| Mass | ~13.8 g |
| Dimensions | ~22.8 × 12.2 × 25.6 mm |
| Control | standard PWM, 50 Hz, 1–2 ms pulse |

**Purpose unconfirmed** — working assumption is a wheel brake for jump-up. ⚠️ **Timing concern:** at 0.08 s/60°, a clamp stroke could take 50–80 ms against a pendulum time constant of ~114 ms. The impulsive-brake model assumes the transfer is *fast* relative to the dynamics. Needs mechanical advantage and short travel; **measure actual clamp time on the jig.** See [[System Integration - Full Cube]] §8.2.

---

## 2. Sensing

### 2.1 mjbots MA600 breakout — wheel encoder ×3

| Parameter | Value |
|---|---|
| Sensor | MPS MA600, **TMR** (tunnel magnetoresistance) |
| Type | **absolute** angle, full 360° |
| Resolution | up to **16-bit** absolute angle over SPI |
| Interface | **SPI**, 3.3 V |
| Connector | GH6; ships with **GH6→GH7 cable** for moteus AUX2 |
| Included | sense magnet |

**Why MA600 rather than the moteus's built-in encoder:** lower noise and better linearity than hall-effect sensors (AS5047P, AS5600, MA702, MA732), and — the practical reason — it lets the encoder sit at the shaft while the moteus board lives anywhere within cable reach.

> ⭐ **The finding that matters for CAD: the MA600 supports off-axis mounting.** mjbots specifically developed off-axis support using a **diametrically magnetised ring magnet** (they stock 32 × 22 × 4 mm) with the sensor beside it rather than over the shaft end. The chip is placed near the board edge for exactly this.
>
> This **solves the outrunner mounting problem elegantly** — instead of needing access to a rotating shaft end, put a ring magnet around the bell and the sensor alongside. Worth designing around from v0.

> ⚠️ **Requires moteus firmware 2024-10-29 or newer.** Check and update before bring-up.

Also reported: less audible noise at the same encoder bandwidth and control gains.

### 2.2 SparkFun BMI270 — IMU ×1

| Parameter | Value |
|---|---|
| Type | Bosch 6-DoF (3-axis gyro + 3-axis accel) |
| Gyro range | ±125 to ±2000 °/s |
| Accel range | ±2 to ±16 g |
| Interfaces | I²C **and SPI** |
| Voltage | 3.3 V |

⚠️ **To verify:** (a) does the SparkFun Qwiic breakout expose the **SPI pins**? We want SPI, not I²C, at 1 kHz. (b) Configured **output data rate** — this may be the loop-rate ceiling rather than the Teensy.

Configure gyro to **±2000 °/s** — jump-up spins fast and clipping destroys the estimate.

---

## 3. Compute and communications

### 3.1 Teensy 4.1 — flight computer ×1

| Parameter | Value |
|---|---|
| MCU | NXP i.MX RT1062, **ARM Cortex-M7 @ 600 MHz**, hardware FPU |
| RAM / Flash | 1024 KB / 8 MB |
| I/O | 55 pins, 35 PWM-capable |
| Serial / SPI / I²C | 8 / 3 / 3 |
| CAN | 2× CAN 2.0B + **1× CAN-FD** |
| **Storage** | **built-in microSD socket** |
| Logic | **3.3 V, NOT 5 V tolerant** |
| Dimensions | 61 × 18 mm |
| Toolchain | Arduino IDE + Teensyduino |

Peripheral budget: 3 SPI buses covers a dedicated IMU bus with room to spare; the microSD is our high-rate logging path (see [[System Integration - Full Cube]] §2.6).

### 3.2 CAN-FD adapter ×1
Transceiver breakout for the Teensy's CAN-FD peripheral. The Teensy provides the controller; this provides the physical layer to the bus.

### 3.3 mjbots mjcanfd-usb-1x ×1
USB↔CAN-FD adapter. **Ground support only** — laptop taps the same bus for `moteus_tool` calibration and `tview` debugging. Not on the cube in the final demo.

### 3.4 Seeed XIAO ESP32-C6 + antenna ×1

| Parameter | Value |
|---|---|
| MCU | ESP32-C6, RISC-V |
| Radio | Wi-Fi 6, BLE 5, Zigbee/Thread |
| Dimensions | ~21 × 17.5 mm |
| Logic | 3.3 V |

Telemetry only, on UART as a **side branch**. Never in the control loop — a blocking Wi-Fi send that stalls the 1 kHz loop is a fall.

### 3.5 JST PH3 cables ×≥4
3-pin, 2.0 mm pitch. CAN daisy chain: CAN_H, CAN_L, GND. Each moteus ships with one housing + crimps.

---

## 4. Power

### 4.1 Turnigy Heavy Duty 6S 3600 mAh 60C

| Parameter | Value |
|---|---|
| Chemistry / cells | LiPo, **6S** (6 cells in series) |
| Nominal voltage | 22.2 V |
| **Full charge** | **25.2 V** ← the number that kills 16 V capacitors |
| Min safe | 19.8 V (3.3 V/cell); 18 V absolute floor |
| Capacity | 3600 mAh ≈ **80 Wh** |
| Discharge | 60C ≈ 216 A (vastly more than we need) |
| Length | **139 mm** ← hard structural constraint |
| Connector | XT90 |

⚠️ **Verify by weighing** — estimated ~530–600 g from energy density, which would be ~40% of the cube's mass. Also **measure the other two dimensions** (width, height) for diagonal-fit clearance.

**Worth asking the mentor:** a 1500 mAh 6S pack would weigh ~220 g and be shorter. Our draw is ~10–50 W; 80 Wh runs the cube for over an hour when we need 20–30 minutes. That single swap saves ~300 g and relaxes both constraints.

### 4.2 LM2596 buck converter ×1

| Parameter | Value |
|---|---|
| Input | 4.5–40 V |
| Output | adjustable 1.23–37 V |
| Current | 3 A peak, **~2 A continuous realistic** without heatsinking |
| Switching | 150 kHz |
| Efficiency | ~75–88 % |

⚠️ At 22 V → 5 V the step-down ratio is large and it will **get hot**. Budget the 5 V loads (Teensy, ESP32, servo stall, IMU) and check against 2 A. If tight, a modern synchronous buck would be a worthwhile upgrade.

### 4.3 XT90 connector pair
~90 A rated. ⚠️ **The BOM has XT90 only, but each moteus uses XT30** — need 3+ XT30 pairs. Also strongly recommend an **XT90-S anti-spark** variant for the main connection: connecting bulk capacitance to a charged 6S pack draws a large inrush and arcs the contacts.

### 4.4 1N5819 Schottky diode ×1–2
40 V, 1 A, forward drop ~0.45 V. Uses: reverse-polarity protection, power-ORing between bench supply and battery, or servo flyback. ⚠️ Confirm intent — 40 V is fine on a 25.2 V bus but **1 A limits it to signal-level duty**, not the motor bus.

---

## 5. Passives and hardware

### 5.1 CAN termination: 60.4 Ω ×4 + 4.7 nF ×2 — **split termination**

Standard CAN needs 120 Ω at each end of the bus. **Split termination** replaces each 120 Ω with two 60.4 Ω in series and a capacitor from the midpoint to ground:

```
CAN_H ──[60.4Ω]──┬──[60.4Ω]── CAN_L
                 │
              [4.7nF]
                 │
                GND
```

2 × 60.4 = 120.8 Ω ✓ (60.4 Ω is the standard E96 value nearest 60). The capacitor shunts **common-mode noise** to ground — meaningfully better EMC than plain termination, which matters with three switching motor drivers on the same harness.

BOM quantities confirm the intent: **4 resistors + 2 capacitors = 2 networks**, one at each physical end of the bus.

### 5.2 Capacitors

| Part | Purpose | Note |
|---|---|---|
| **100 µF 16 V** electrolytic, 105 °C | **5 V rail only** | ⚠️ **Cannot touch the motor bus** — 25.2 V full charge would destroy it. 105 °C rating is good (long life). |
| **100 nF 50 V** ×6–10 | decoupling, per IC | standard practice |
| **4.7 nF** ×2 | CAN split termination | see §5.1 |

⚠️ **Missing from the BOM:** motor-bus **bulk capacitance, 470–1000 µF, ≥50 V, low-ESR**. Decelerating wheels regenerate onto the bus; without bulk capacitance the voltage spikes and drivers fault — which looks exactly like a random controller failure. High-consequence gap.

### 5.3 Perfboard 15 × 9 cm, double-sided
Power distribution and interconnect. Double-sided helps for a ground plane.

---

## 6. Mass budget (electronics)

| Item | Qty | Unit | Total |
|---|---|---|---|
| MN4006 motor | 3 | 66 g | 198 g |
| moteus-n1 | 3 | 14.6 g | 44 g |
| MA600 breakout + magnet | 3 | ~2 g* | 6 g |
| Teensy 4.1 | 1 | ~11 g* | 11 g |
| CAN-FD adapter | 1 | ~5 g* | 5 g |
| XIAO ESP32-C6 | 1 | ~3 g* | 3 g |
| BMI270 breakout | 1 | ~3 g* | 3 g |
| MG92B servo | 1 | 13.8 g | 14 g |
| LM2596 module | 1 | ~10 g* | 10 g |
| Perfboard + passives | — | — | ~40 g* |
| Wiring, connectors | — | — | ~50 g* |
| **Subtotal (no battery)** | | | **~384 g** |
| **Battery** | 1 | ~550 g* | **~550 g** |
| **Total electronics** | | | **~934 g** |

\* estimate — **weigh everything**. Add wheels (~180–270 g) and structure (~250 g) on top.

⚠️ This lands the cube near **1.3–1.4 kg**, well above the 900 g working target. The battery alone is ~40%. This is the single strongest argument for asking about a smaller pack.

---

## 7. Open items

- [ ] **Weigh the battery**; measure width and height
- [ ] Confirm motor quantity — 3 or 4 (spare)?
- [ ] Confirm the **servo's purpose** with the mentor
- [ ] Confirm SparkFun BMI270 breakout exposes **SPI**
- [ ] Confirm BMI270 configured **ODR**
- [ ] Check **moteus firmware ≥ 2024-10-29** for MA600 support
- [ ] Confirm whether moteus reports **bus voltage** in the reply frame
- [ ] Source: **XT30 pairs ×3**, **≥50 V bulk capacitor**, XT90-S anti-spark, inline fuse
- [ ] Confirm 1N5819 intent
- [ ] Decide MA600 mounting: **off-axis with ring magnet** (recommended) vs on-axis

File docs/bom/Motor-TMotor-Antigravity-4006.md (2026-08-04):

---
tags: [space-challenge, sofia, cubli, motor, hardware, structure, cad]
---

# Motor: T-Motor Antigravity MN4006 380KV

Reference sheet for the team. **Part 1** = what the motor is. **Part 2** = what that forces on the structure. Everything in Part 2 is a CAD input.

Driver/encoder pairing is confirmed from the BOM: **moteus-n1 + MA600 per motor** — torque-mode FOC with absolute rotor feedback, which is what the control architecture assumes.

---

## Part 1 — Specifications

### Verified (datasheet or exact derivation)

| Parameter | Value | Note |
|---|---|---|
| KV | 380 rpm/V | datasheet |
| **Torque constant $K_t$** | **0.02513 N·m/A** | $= 9.5493 / \mathrm{KV}$, exact |
| Configuration | 18N24P → **12 pole pairs** | matters for FOC commutation |
| Stator | 40 mm × 6 mm | mounting footprint |
| Shaft | 4 mm | wheel hub bore |
| Mass | **66 g** each | ×3 = 198 g |
| Battery | 4–6S LiPo | BOM supplies 6S |
| No-load speed | ~5 600 rpm (4S) → **~8 400 rpm (6S)** | $= \mathrm{KV} \times V$ |

### Estimated — must be measured or confirmed

| Parameter | Estimate | How to resolve |
|---|---|---|
| Continuous torque $\tau_{\max}$ | ~0.12 N·m | thermally limited; **measure motor temperature under load** |
| Peak torque $\tau_{\text{peak}}$ | ~0.40 N·m | ~16 A brief |
| Rotor inertia $J_{\text{rotor}}$ | ~1×10⁻⁵ kg·m² | not published; small vs. wheel, low priority |
| Phase resistance $R$ | ~0.15 Ω | **multimeter, 10 seconds** |
| Phase inductance $L$ | unknown | LCR meter; sets electrical time constant |

⚠️ **Thermal note:** these are multirotor motors, rated assuming propeller airflow. A reaction wheel provides **none**. Real continuous torque is therefore lower than any propeller-based rating suggests. Treat 0.12 N·m as provisional and watch temperature during testing.

Also: available torque falls at high speed (back-EMF), so the constant-$\tau_{\max}$ assumption is optimistic near 8400 rpm. Fine for balancing (which lives near zero wheel speed), relevant for jump-up spin-up.

---

## Part 2 — What this means for the structure

### 2.1 Mass budget

**198 g of motors** (3 × 66 g), located on three faces. This is a fixed, non-negotiable ~20% of a 1 kg cube, positioned away from the centre — so it drives both total mass **and** the inertia tensor.

### 2.2 Mounting — these are outrunners

The **base is stationary and bolts to the structure**; the **bell rotates** and carries the wheel. Consequences:

- Three motor mounts, on **three mutually orthogonal faces** meeting at the pivot corner. Orthogonality matters — misalignment appears as cross-axis coupling in the controller.
- Each mount carries the **full reaction torque** into the frame. **Printed brackets flex, and that compliance is an unmodelled resonance that caps control bandwidth.** Print for prototyping; plan for aluminium if the loop turns out twitchy.
- Verify the **bolt pattern** (standard multirotor base, likely M3) before designing brackets.
- **Leave airflow around the motors** — no tight enclosure. See the thermal note above.

### 2.3 Wheel interface

- Wheel mounts to the **bell**, at the prop interface.
- **4 mm shaft** — hub bore, if the design uses the shaft rather than the bell face.
- Wheel design targets for a ~120 mm cube: **outer radius ~55–58 mm, ~60 g each, rim-weighted (mass concentrated at the rim, not a solid disc).**
- **Design the hub so rim mass can be added later.** Start light for the pass criterion; bolt on additional rings only if measured jump-up margin requires it. This also covers the material decision — printed rings first, steel rims swapped in without touching the hub.

### 2.4 Encoder mounting — the fiddly geometric constraint

The MA600 sensor must sit **stationary**, facing a **diametric magnet on the rotating part**, with a small and *repeatable* air gap (~0.5 mm — confirm against the MA600 datasheet).

On an outrunner this is genuinely awkward and needs solving early, because it dictates how the motor attaches:

- Magnet carrier must be **non-ferrous** and **concentric** — eccentricity becomes angle error, which becomes bad commutation and torque ripple.
- Keep the sensor as far as geometry allows from the **rotor's own magnets** (the bell is full of them, millimetres away, and the sensor reads a weak field direction).
- Keep the **steel wheel rim** geometrically distant from the sensor too.
- **Slotted mounting holes** for gap adjustment — this will not be right first try.
- Verify a clean, monotonic reading over a full revolution **with the wheel installed**, not just a bare motor.

### 2.5 Cube envelope implied by these motors

The motors are **not** the binding constraint on cube size — torque headroom is generous. The binding constraint is **jump-up momentum**, which degrades with both size and mass:

| Cube | Jump margin (flat→edge) |
|---|---|
| 110 mm, 900 g | ×2.22 |
| 120 mm, 900 g | ×1.95 |
| 120 mm, ~1.3 kg | ×1.34 |
| 150 mm, ~1.3 kg | **×0.96 — fails** |

Need ×1.3+ to schedule jump-up as a deliverable.

**Design target: ≤120 mm side, mass as low as achievable.** Smaller improves hold angle, catch angle *and* jump margin simultaneously — the only cost is a marginally faster control loop, which the Teensy absorbs easily. Practical floor ~110 mm, set by the room needed for large-radius wheels.

---

## Open items

- [ ] Measure phase resistance (multimeter)
- [ ] Confirm bolt pattern for bracket design
- [ ] Confirm MA600 datasheet air gap tolerance
- [ ] Measure motor temperature under sustained load — validates the 0.12 N·m assumption
- [ ] Confirm whether the BOM supplies 4 motors (3 + spare) or exactly 3

Sizing tool: `cubli_sizing.m` in `Documents/MATLAB/Space Challenge 2026`. Companion notes: [[Structural Constraints]], [[System Integration - Full Cube]], [[CAD Handoff - fill on BOM]].

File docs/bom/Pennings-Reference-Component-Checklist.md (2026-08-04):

---
tags: [space-challenge, sofia, cubli, hardware, bom, checklist]
---

# Pennings Reference Build + Component Checklist

Two things: (1) assessment of the open-source Willem Pennings balancing cube as a reference, (2) the complete component checklist and exactly which datasheet numbers to extract tomorrow.

---

# Part 1 — The Pennings balancing cube

**Repo:** https://github.com/willem-pennings/balancing-cube (~1.1k stars, GPL-3.0)
**Write-up:** https://willempennings.nl/balancing-cube/

## What it is

A corner-balancing reaction-wheel cube, reverse-engineered and drawn from scratch because the earlier work (ETH Cubli and others) was largely closed-source. It balances on a corner and can simultaneously rotate about its vertical axis under control. Repo contains `bom/`, `configuration/`, `electronics/`, `mechanical/`, `measurements/`, `software/`.

**Toolchain:** Fusion 360 (mechanical), KiCad 7 (PCBs), Arduino IDE (code, C++), Maxon motors + ESCON drivers tuned via Escon Studio, ESP32 as the microcontroller.

## Yes, this is very useful — here's specifically how

1. **`measurements/` is the most valuable folder for us.** Real parameter-identification data from a working cube. It's a ground-truth cross-check on our own free-swing and spin-down identification (see [[Deriving Dynamics from CAD]] §4) and a sanity check that our inertia numbers are the right order of magnitude.
2. **`mechanical/` (Fusion 360) as a design reference, not a copy.** Look specifically at how he solved: wheel-to-motor mounting, the corner pivot tip, frame stiffness with printed parts, cable routing. These are the details that cost days if you rediscover them.
3. **`bom/`** — validates our component checklist below and reveals parts we might forget.
4. **`electronics/` (KiCad)** — motherboard schematic shows power distribution, regulation, and how the ESP32/driver/IMU interconnect. Useful even if EnduroSat hands us different parts.
5. **`software/`** — his controller structure, calibration routines, and parameter file. **Read it, don't paste it** (see license warning).
6. **He points at Bobrow et al. (University of São Paulo)**, who reduce the required IMU count from six (ETH's design) to **one**. That's a meaningful simplification for us — one good IMU instead of six mediocre ones. Worth chasing the paper tomorrow; verify the citation before using it.

## Three cautions — read before the team gets attached to it

**⚠️ 1. GPL-3.0 is copyleft.** If we incorporate his code into our firmware, our firmware must also be released under GPL-3.0. That's usually fine for a student challenge, **but EnduroSat is a company and may have expectations about IP on work produced in their programme.** Ask them tomorrow. The safe default: read his code for architecture and technique, write our own. Treat the repo as documentation, not as a library. (Mechanical CAD under GPL is legally murkier but the same principle applies — use as reference, draw our own.)

**⚠️ 2. His hardware stack is probably not our hardware stack.** He uses Maxon motors with ESCON drivers (industrial, expensive, current-mode, tuned in proprietary software) and an ESP32. EnduroSat is giving us their own motors, batteries, and a Raspberry Pi. Gains, wheel geometry, and driver interface will **not** transfer. Architecture, calibration procedure, and mechanical solutions will.

**⚠️ 3. Reproducing it is not trivial — and the known failure mode is exactly the one I warned about.** A hardware engineer who rebuilt the cube from his files reports on his site: balance holds for roughly 7–8 seconds, then falls when it attempts static balance with rotation; after parameter changes, roughly one attempt in twenty succeeds and any small disturbance topples it.

That "works for ~8 seconds then falls" signature is textbook **wheel momentum saturation from a COM offset** ([[Sizing Memo]] §5): the wheel absorbs the bias torque until it runs out of speed, then the cube has no authority left. It confirms two of our design rules are not optional — physically shim the COM, and penalise wheel momentum in the LQR cost. Also note his mention of accelerometer calibration files: **IMU calibration is a required step, not a nice-to-have.**

**Recommendation:** clone the repo tonight, have the CAD subteam study `mechanical/` and `bom/` tomorrow, and have me go through `measurements/` and `software/` architecture. Do not plan to fork it.

---

# Part 2 — Component checklist for tomorrow

Organised by subsystem. **Bold = ask EnduroSat explicitly.** For each, the datasheet numbers we actually need and why.

## 2.1 Actuation

### Motors (×3) — **provided**
| Parameter | Symbol | Why we need it |
|---|---|---|
| Torque constant | $K_t$ [N·m/A] | Converts our torque command to current; sizing memo input |
| **Max continuous torque** | $\tau_{\max}$ | **Sets max cube mass — CAD is blocked on this** |
| Peak/stall torque | $\tau_{\text{peak}}$ | Jump-up feasibility |
| **Max speed** | $\omega_{\max}$ [rpm] | Momentum capacity $h_{\max}=I_w\omega_{\max}$ |
| **Rotor inertia** | $J_{\text{rotor}}$ [g·cm²] | Adds to wheel inertia; often buried or omitted |
| Terminal resistance | $R$ [Ω] | Power/thermal budget |
| Terminal inductance | $L$ [mH] | Current-loop bandwidth |
| Pole pairs | — | Required for FOC commutation |
| Hall sensors present? | — | Wheel speed feedback without a separate encoder |
| Mass | $m_{\text{motor}}$ | COM and inertia budget |
| Nominal voltage | — | Must match battery |

*If rotor inertia isn't listed, ask Maxon-equivalent datasheets or estimate; it's usually small versus the wheel but not negligible.*

### Motor drivers (×3) — **provided?**
**The single most important question tomorrow.**
| Parameter | Why |
|---|---|
| **Control modes** | Current/torque mode is what our whole model assumes. Speed-only ESC changes the plant, the linearisation, and the gains |
| **Command interface** | Analog? PWM? UART/CAN/SPI? Determines MCU wiring and latency |
| Current loop bandwidth | Sets $\tau_{\text{lag}}$ in the model; want ≫ our 500 Hz outer loop |
| Continuous / peak current | Must cover $\tau_{\max}/K_t$ |
| Supply voltage range | Battery compatibility |
| **Regenerative handling** | Decelerating a wheel pumps energy back — see §2.4 |
| Encoder/Hall input support | Wheel speed feedback path |
| Configuration software needed? | Maxon needs ESCON Studio; adds a setup day if so |

### Reaction wheels (×3) — **we fabricate**
Not a purchased part but a design deliverable. Maximise inertia per unit mass → **rim-weighted**, not solid discs. Printed hub with a press-fit or bolted metal ring (brass/steel) is the standard student solution.
- Need: outer radius, rim mass, hub material, **balance quality** (an unbalanced wheel at 8000 rpm shakes the IMU — see §2.2)
- Need: **hub/coupling to the motor shaft** — set-screw hub, keyed, or clamping. Easy to forget; blocks assembly if missing.

## 2.2 Sensing

### IMU — **check if provided; likely we source**
Per Bobrow et al., **one good IMU** may be enough (vs. ETH's six).
| Parameter | Target / why |
|---|---|
| **Gyro range** | ≥ ±2000 °/s — jump-up spins fast; clipping ruins the estimate |
| Gyro noise density | [°/s/√Hz] — feeds Kalman tuning |
| Gyro bias stability / random walk | Dominant error source in attitude drift |
| Accel range | ±8 g typical |
| Accel noise density | Kalman tuning |
| **Max output data rate** | ≥ 1 kHz so it doesn't bottleneck the loop |
| **Interface** | **SPI strongly preferred over I²C** — I²C at 1 kHz with three devices gets marginal |
| Built-in DLPF / FIFO | Helps with wheel vibration |
| Temperature sensitivity | Bias drifts as motors heat the frame |

**Mounting matters as much as the part:** soft-mount, keep away from motors, and record its position in the body frame — the lever arm shows up in the accelerometer measurement model.

### Wheel speed feedback
Hall sensors (usually integrated in BLDC) or encoders. Need: counts per revolution, interface, and whether the driver exposes speed or we read it directly.

### Current sensing
Usually inside the driver. If exposed, it gives us actual applied torque — extremely useful for validating the torque command and measuring $\eta_{\text{brake}}$.

## 2.3 Compute — **provided (Raspberry Pi)**
Ask, in this order:
1. **Which board?** Pi Pico (MCU, fine) vs Pi 4/5 (Linux, real-time problem — see [[Revised Schedule - Provided Hardware]] §2).
2. **Is a microcontroller available alongside?** For the split architecture.
3. Available interfaces: SPI, UART, PWM, CAN?
4. Programming/debug setup — do we get a debugger, or is it USB-only?

Plus: **oscilloscope or logic analyser** for measuring loop jitter. Not optional — we need to *prove* the loop rate, not assume it.

## 2.4 Power — **provided (battery)**
| Item | What to ask |
|---|---|
| Battery | Nominal voltage, cell count, capacity [Ah], **max continuous discharge (C)** — must cover 3 motors at peak |
| | **Max charge rate** — reaction wheels regenerate on deceleration |
| | Mass and dimensions — drives COM |
| | Connector type |
| BMS / protection | Present? Does it cut out on regen overvoltage? |
| Regulators | Motor bus → 5 V → 3.3 V. Current capacity for Pi (a Pi 4/5 wants ~3 A!) |
| **Bulk capacitance** | Across the motor bus, to absorb regenerative spikes. Commonly forgotten; causes driver overvoltage faults |
| Power switch + fuse | Safety, and you *will* want a fast kill switch |
| Emergency stop | See safety below |

**Regenerative braking is a real design item here.** Every time a wheel decelerates it acts as a generator. A LiPo will normally absorb it, but if there's a protection circuit that blocks charge current, bus voltage spikes and drivers fault out — which looks like a random controller failure. Ask about it tomorrow.

## 2.5 Mechanical / structural
| Item | Note |
|---|---|
| Frame | 3D printed — **measure effective density on a coupon** ([[Deriving Dynamics from CAD]] §2.3) |
| **Corner pivot tip** | A printed corner deforms and wears within hours. Needs a **hardened insert** — steel ball, dowel pin, or ground tip. Easy to overlook, kills repeatability |
| **Balancing pad** | Needs *friction* so the corner doesn't slip. Rubber/silicone mat. Pennings uses a dedicated pad |
| Bearings | If the wheel shaft isn't fully motor-supported |
| Fasteners | Heat-set inserts for printed parts (threading plastic directly fails under vibration) |
| Cable management | Contributes mass asymmetrically → COM offset → momentum saturation |
| **Wheel guards** | Pennings explicitly recommends this: thin discs over the spinning flywheels to prevent trapped fingers. **Three wheels at 8000 rpm in a room of 15 people — do this** |
| Shim/ballast provision | Small screws or weights to trim the COM after assembly. Design it in |

## 2.6 Test equipment
- **1D pendulum jig** (arm + one wheel) — highest-value item of week 1
- Precision scale (COM and mass measurement)
- Bench power supply (debug without draining the battery)
- Multimeter, oscilloscope/logic analyser
- Soft landing surface — the cube *will* fall over, repeatedly
- Tether/soft rig for first corner attempts
- Camera on a tripod — film everything from day 1

---

## The three questions that block everyone else tomorrow
1. **Driver control mode** — torque/current, or speed only?
2. **Which Raspberry Pi**, and is an MCU available alongside?
3. **Motor $\tau_{\max}$, $\omega_{\max}$, $K_t$, rotor inertia** — the sizing script inputs; CAD is blocked until these exist.

Everything else can wait a day. These three cannot.

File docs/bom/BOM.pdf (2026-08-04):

## Bill of Materials — 3 Teams

Category | Product / Specification | Supplier Link
DC Motor | T-Motor MN4006 KV380 — 2 pcs per set | https://
Driver | mjbots moteus-n1 | https://
Encoder | mjbots MA600 Breakout + magnet | https://
MCU | Teensy 4.1 | https://
CAN-MCU | Single CAN-FD adapter for Teensy 4.1 | https://
CAN-USB | mjcanfd-usb-1x | https://
CAN cable | JST PH3 cable | https://
Wi-Fi | Seeed Studio XIAO ESP32-C6 with antenna | https://
Resistor | 60.4 Ω, 1/2 W, through-hole resistor for CAN | https://
IMU | SparkFun 6DoF IMU Breakout — BMI270 | https://
Servo | TowerPro MG92B servo | https://etop.bg/
Battery | Turnigy Heavy Duty 6S 3600 mAh, 22.2 V, 60C | https://
DC-DC | LM2596 step-down voltage regulator | https://
Connector | XT90 connector pair | https://
Capacitor | 100 µF, 16 V electrolytic capacitor, 105°C | https://
Capacitor | 100 nF, 50 V capacitor | https://
Capacitor | 4.7 nF capacitor for CAN | https://
Perfboard | 15 × 9 cm, green, double-sided | https://
Diode | 1N5819 Schottky diode | https://

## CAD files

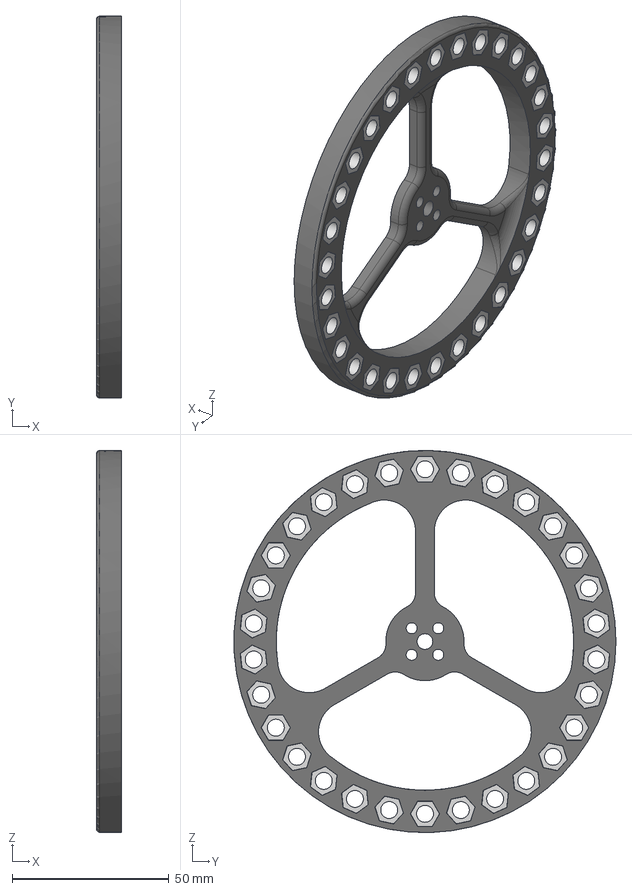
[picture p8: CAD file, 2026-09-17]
simulation/cube-3d/cad/nemesis/Cubli_Xwheel_Final.step
8.00 x 122.0 x 122.0 mm

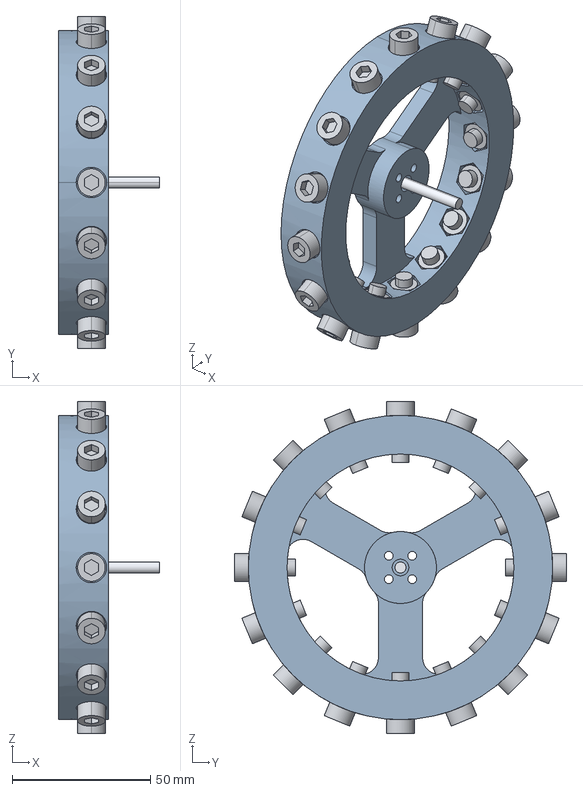
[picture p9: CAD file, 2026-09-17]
simulation/cube-3d/cad/WHEEL_X.step
36.5 x 120.0 x 120.0 mm
x_wheel
x_shaft
x_screw_00
x_nut_00
x_screw_01
x_nut_01
x_screw_02
x_nut_02
x_screw_03
x_nut_03
x_screw_04
x_nut_04
x_screw_05
x_nut_05
x_screw_06
x_nut_06
x_screw_07
x_nut_07
x_screw_08
x_nut_08
x_screw_09
x_nut_09
x_screw_10
x_nut_10
x_screw_11
x_nut_11
x_screw_12
x_nut_12
x_screw_13
x_nut_13
x_screw_14
x_nut_14
x_screw_15
x_nut_15

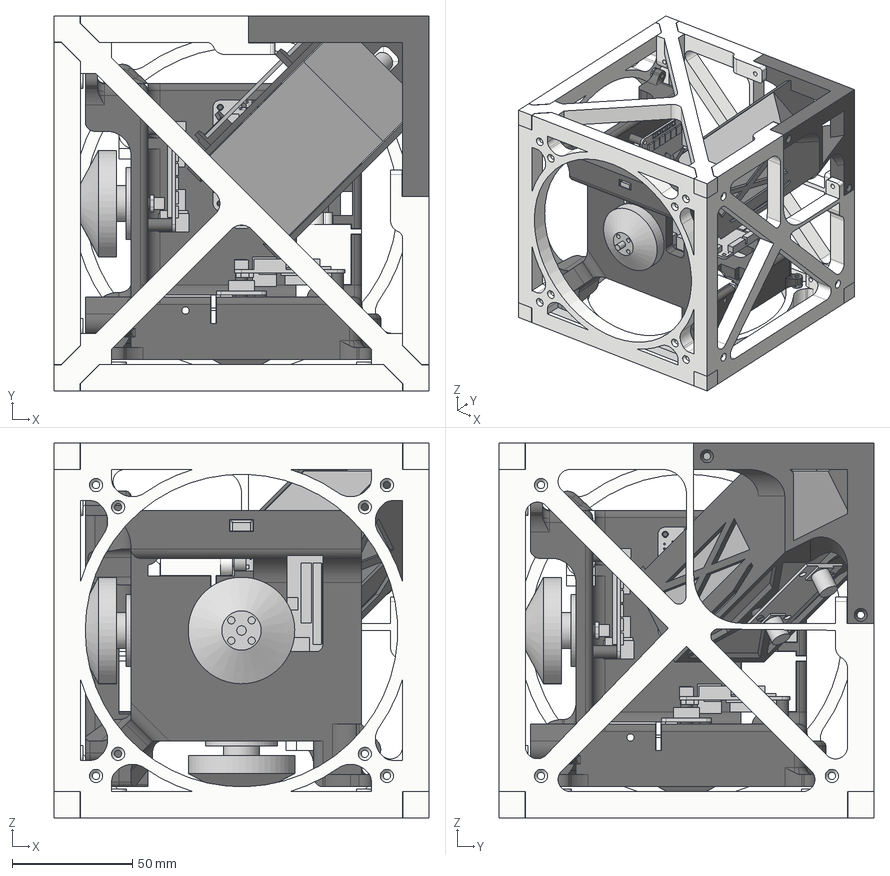
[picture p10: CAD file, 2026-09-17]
simulation/cube-3d/cad/nemesis/Cubli_Frame_Final.step
156.0 x 156.0 x 156.0 mm

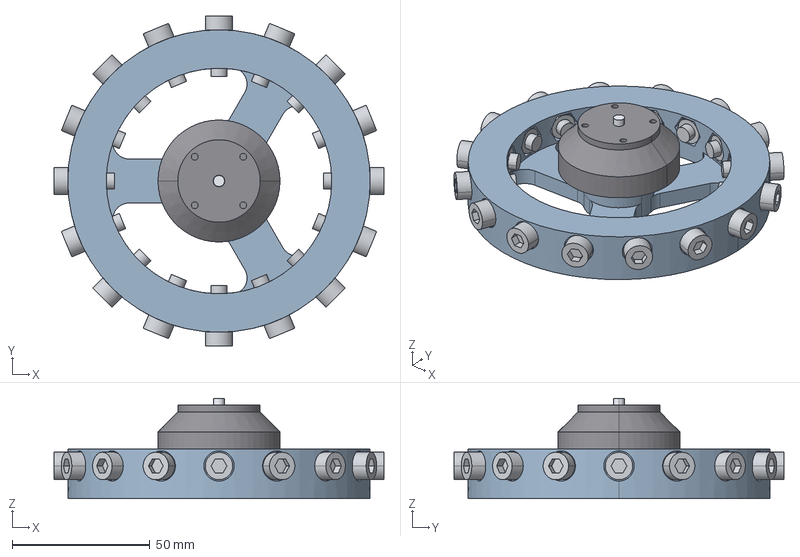
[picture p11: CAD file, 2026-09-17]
simulation/cube-3d/cad/WHEEL_Z.step
120.0 x 120.0 x 36.5 mm
z_wheel
z_motor
z_shaft
z_screw_00
z_nut_00
z_screw_01
z_nut_01
z_screw_02
z_nut_02
z_screw_03
z_nut_03
z_screw_04
z_nut_04
z_screw_05
z_nut_05
z_screw_06
z_nut_06
z_screw_07
z_nut_07
z_screw_08
z_nut_08
z_screw_09
z_nut_09
z_screw_10
z_nut_10
z_screw_11
z_nut_11
z_screw_12
z_nut_12
z_screw_13
z_nut_13
z_screw_14
z_nut_14
z_screw_15
z_nut_15

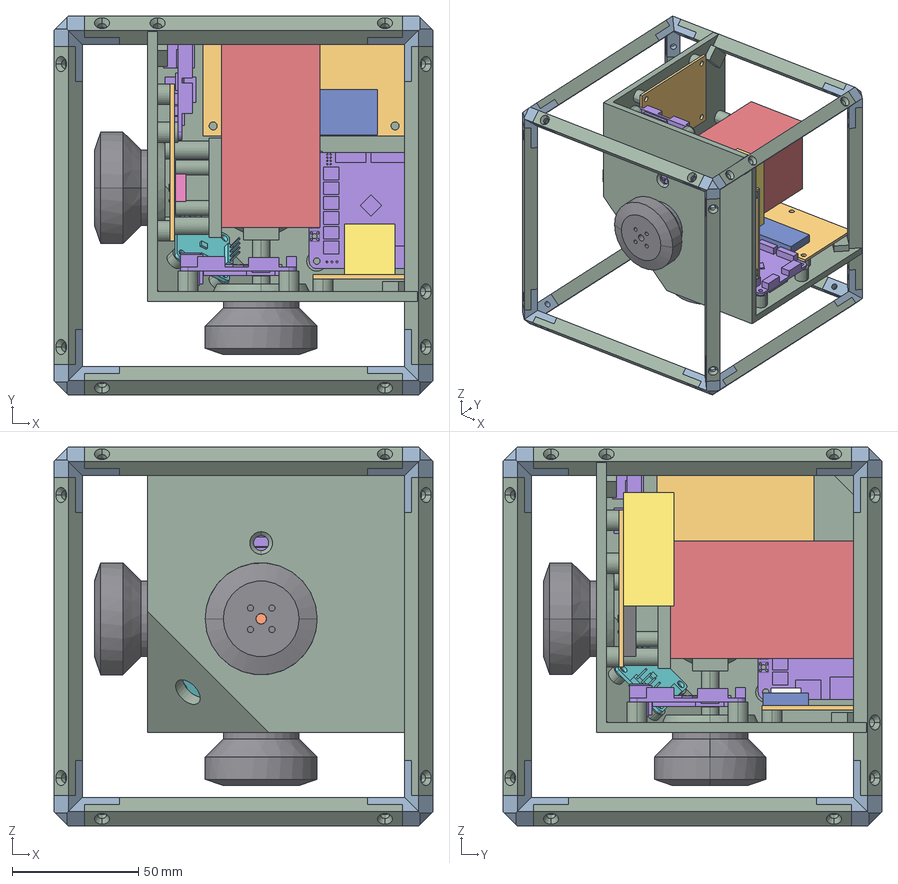
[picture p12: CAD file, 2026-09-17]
simulation/cube-3d/cad/FRAME.step
150.0 x 150.0 x 150.0 mm
CUBI
IMU_BMI270
corner_000
corner_110
corner_101
corner_011
corner_100
corner_010
corner_001
corner_111
beam_00
beam_01
beam_02
beam_03
beam_04
beam_05
beam_06
beam_07
beam_08
beam_09
beam_10
beam_11
sleeve_z
magnet_z
ma600_z
ma600_bracket_z
moteus_n1_z
sleeve_x
magnet_x
ma600_x
ma600_bracket_x
moteus_n1_x
sleeve_y
magnet_y
ma600_y
ma600_bracket_y
moteus_n1_y
battery
perf_z
teensy41_z
usb_teensy_z
perf_x
perf_y
xiao_esp32c6_y
xt90_y
z_motor
x_motor
y_motor

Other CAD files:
simulation/cube-3d/cad/nemesis/Cubli_Ywheel_Final.step
simulation/cube-3d/cad/WHEEL_Y.step
simulation/cube-3d/cad/nemesis/Cubli_Zwheel_Final.step

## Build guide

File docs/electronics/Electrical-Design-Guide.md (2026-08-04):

---
tags: [space-challenge, sofia, cubli, electronics, schematic, kicad, wiring]
---

# Electrical Design Guide — schematic, wiring, KiCad

Complete reference for drawing the electronic (schematic) and electrical (wiring) diagrams. Every connection, pin, and passive.

Components: [[Component Reference]]. Architecture rationale: [[System Integration - Full Cube]]. Physical placement: [[Structural Constraints]].

---

## 1. Architecture in one line

**Teensy 4.1 → CAN-FD → 3× moteus-n1 → 3× MN4006**, each driver closing its own current loop with its own MA600 encoder. One BMI270 IMU on SPI. ESP32-C6 on UART for telemetry only. Everything from one 6S pack via two rails.

Four subsystems, drawn as four schematic sheets:
1. **Power** — battery, protection, motor bus, 5 V rail
2. **CAN bus** — transceiver, chain, termination
3. **Compute & sensing** — Teensy, IMU, ESP32
4. **Drivers** — 3× moteus with encoders (mostly connectors)

---

## 2. Power distribution

```
6S LiPo  (22.2 V nom / 25.2 V full / 18 V floor)
   │
   ├─ XT90-S anti-spark  ← inrush limiting on connect
   ├─ Main switch / E-STOP    ⚠ must break the MOTOR bus, not just logic
   ├─ Fuse ~30 A slow-blow
   │
   ├──► MOTOR BUS (22–25 V) ──┬── XT30 ──► moteus #1
   │         │                ├── XT30 ──► moteus #2
   │         │                └── XT30 ──► moteus #3
   │         └── BULK CAP 470–1000 µF ≥50 V low-ESR   ⚠ NOT IN BOM
   │
   └──► LM2596 (22 V → 5 V) ──► 5 V RAIL
              │                    ├──► Teensy VIN
              │                    ├──► ESP32-C6 5 V pin
              │                    └──► Servo V+  (local 100 µF)
              └── 100 µF 16 V on OUTPUT side only
                                   │
                     Teensy 3.3 V out (≤250 mA) ──► BMI270, CAN transceiver
```

### 2.1 ⚠️ Two hazards to get right

**The 100 µF 16 V capacitors go on the 5 V rail only.** A fully charged 6S pack is **25.2 V**. A 16 V electrolytic on the motor bus will fail, possibly violently. Mark this on the schematic explicitly.

**The motor-bus bulk capacitor is missing from the BOM.** Decelerating wheels regenerate onto the bus; without bulk capacitance the voltage spikes and drivers fault out — presenting as *random controller failures* that look like software bugs. Source **470–1000 µF, ≥50 V, low-ESR**, and place it physically close to the moteus power taps, not at the battery end.

### 2.2 LM2596 loading

| Load | Typical | Peak |
|---|---|---|
| Teensy 4.1 @600 MHz | ~150 mA | 200 mA |
| ESP32-C6 | ~100 mA | 300 mA (Wi-Fi TX) |
| BMI270 | ~1 mA | — |
| Servo MG92B | ~10 mA idle | ~1 A stall |
| **Total** | **~400 mA** | **~1.5 A** |

Within the LM2596's realistic 2 A continuous, but at 22→5 V it dissipates real power and will run warm. **Give the servo its own local 100 µF** so stall inrush doesn't sag the Teensy rail and reset the MCU mid-balance.

### 2.3 Wire gauge and protection

| Run | Gauge |
|---|---|
| Battery → bus | 14 AWG |
| Bus → each moteus | 18 AWG |
| 5 V rail | 22 AWG |
| Signal | 26–28 AWG |

- **Fuse:** ~30 A slow-blow. Must survive jump-up spin-up current without nuisance blowing.
- **E-stop:** must interrupt the motor bus. A logic-only kill leaves the wheels spinning.
- **1N5819 (40 V, 1 A):** signal-level only — reverse-polarity protection on the 5 V rail or servo flyback. **Cannot protect the motor bus.**

---

## 3. CAN-FD bus

### 3.1 The adapter — confirmed part

**Fusion Tech "Single CAN-FD adapter for Teensy 4.1"** (Tindie). Confirmed specs:

| Property | Value |
|---|---|
| Transceiver | **TI TCAN330G** — CAN-FD to **5 Mbps** ✓ matches moteus |
| Teensy interface | **CAN3 controller, pins 30 / 31** ✓ the only FD-capable one |
| Termination | **120 Ω onboard**, with a **cuttable trace** to disable |
| Library | **FlexCAN_T4** (bundled with Teensyduino) — `github.com/tonton81/FlexCAN_T4` |
| Form factor | backpack, solders onto the Teensy; 3-pin 0.1″ header for the bus |

Backwards compatible with CAN 2.0, so no speed compromise is needed anywhere.

### 3.2 Topology — ONE termination network, not two

Because the adapter is already terminated:

```
[adapter: 120 Ω onboard] ── moteus#1 ── moteus#2 ── moteus#3 ── [2× 60.4 Ω + 4.7 nF]
                                             │
                                  (USB adapter taps mid-chain for debug)
```

⚠️ **Build only ONE split-termination network, at moteus #3.** Fitting both ends would put ~40 Ω on the bus and communication fails outright.

⚠️ **The adapter must sit at a physical END of the chain.** It carries termination, so mid-chain placement breaks the bus. Leave its trace intact for this topology; only cut it if the adapter has to move elsewhere.

Leftover from the BOM: **2× 60.4 Ω + 1× 4.7 nF spare** — keep as rebuild stock.

**Rules:**
- Linear chain, **never a star**.
- Stubs under ~30 cm at 5 Mbps.
- CAN_H / CAN_L as a **twisted pair**, GND alongside.
- Route away from motor phase wires; cross at right angles where unavoidable.

### 3.3 Split termination (at moteus #3 only)

```
CAN_H ──[60.4 Ω]──┬──[60.4 Ω]── CAN_L
                  │
               [4.7 nF]
                  │
                 GND
```

2 × 60.4 Ω = 120.8 Ω ✓ (60.4 Ω is the E96 value nearest 60). The capacitor shunts **common-mode** noise to ground — better EMC than plain 120 Ω, which matters with three switching drivers sharing a harness.

### 3.4 ⚠️ Connector mismatch — plan this before soldering

The adapter's bus side is a **3-pin 0.1″ (2.54 mm) header**. The moteus uses **JST PH3 at 2.0 mm pitch**. **These do not mate.**

Options:
1. Re-crimp one end of a PH3 cable into a 3-way Dupont housing (cleanest).
2. Solder a female header strip to the PH3 cable's bare end.
3. Solder the cable's bare wires directly to the adapter pins, with heatshrink.

First check whether your 30 cm PH3 cables have connectors on **both** ends or one end flying — if one end is bare, option 3 is immediate.

⚠️ **Confirm pin order on both sides before soldering.** A swapped CANH/CANL is *silent* — the bus simply doesn't communicate, with no error pointing at the cause. Write the pinout on the schematic sheet.

### 3.5 Adapter connections

| Adapter | Teensy | Note |
|---|---|---|
| TXD | pin 31 | CAN3 TX |
| RXD | pin 30 | CAN3 RX |
| VCC | 3.3 V | ~35 mA, safe from Teensy regulator |
| GND | signal ground | |
| CANH / CANL / GND | 3-pin header → bus | see §3.4 |

Since it mounts directly on the Teensy, the first four are made by the header — verify they land on 30/31 and not 22/23 or 0/1.

---

## 4. Teensy 4.1 pin map

| Pin | Function | Connects to | Note |
|---|---|---|---|
| 30 | CAN3 RX | Transceiver RXD | **CAN3 is the only FD-capable peripheral** |
| 31 | CAN3 TX | Transceiver TXD | |
| 10 | SPI0 CS | BMI270 CS | |
| 11 | SPI0 MOSI | BMI270 SDI | |
| 12 | SPI0 MISO | BMI270 SDO | |
| 13 | SPI0 SCK | BMI270 SCK | also onboard LED — will flicker |
| 9 | Digital in | BMI270 INT1 | data-ready interrupt |
| 0 | Serial1 RX | ESP32 TX | |
| 1 | Serial1 TX | ESP32 RX | cross-connect |
| 2 | PWM | Servo signal | 50 Hz, 1–2 ms |
| 3 | Digital in | E-stop sense | optional, pull-up |
| 4 | Digital out | Status LED | + series resistor |
| 14 (A0) | Analog in | Battery divider | optional; moteus also reports bus V |
| VIN | 5 V in | LM2596 out | 3.6–5.5 V range |
| 3.3 V | 3.3 V out | IMU, transceiver | ≤250 mA total |
| GND | Ground | signal ground | multiple pins, use several |

**CAN1 and CAN2 are classic CAN only** — do not use them for the moteus bus. The built-in microSD uses dedicated SDIO pins and consumes none of the above.

---

## 5. Sensing and auxiliaries

### 5.1 Encoders — not on the Teensy

Each **MA600 → its own moteus AUX2** (JST GH-7), using the supplied GH6→GH7 cable. The moteus supplies 3.3 V over the same cable.

⚠️ **AUX2 SPI runs at 6 MHz.** Keep each run **under 20 cm**, and route away from that motor's phase wires. This is the constraint that forces each moteus to sit near its own motor.

Requires moteus firmware **2024-10-29 or newer** for MA600 support.

### 5.2 BMI270 IMU

**SPI, not I²C** — I²C at 1 kHz with the noise environment is marginal.

| BMI270 | Teensy |
|---|---|
| CS | 10 |
| SDI (MOSI) | 11 |
| SDO (MISO) | 12 |
| SCK | 13 |
| INT1 | 9 |
| VDD / VDDIO | 3.3 V |
| GND | signal ground |

Add **100 nF** at its supply pin. Configure gyro to **±2000 °/s** — jump-up spins fast and clipping destroys the estimate.

⚠️ Verify the SparkFun Qwiic breakout **exposes the SPI pins** — it is I²C-first.

### 5.3 Servo (MG92B)

| Servo | To |
|---|---|
| Signal (orange) | Teensy pin 2 |
| V+ (red) | 5 V rail, **not** Teensy 3.3 V |
| GND (brown) | signal ground |

Local **100 µF** at the servo connector. Optional 1N5819 across the supply for flyback.

### 5.4 ESP32-C6

| ESP32 | Teensy |
|---|---|
| TX | pin 0 (RX1) |
| RX | pin 1 (TX1) |
| 5 V | 5 V rail |
| GND | signal ground |

Telemetry only — **never in the control path**. Teensy writes must be non-blocking; a stalled Wi-Fi send that blocks the 1 kHz loop is a fall.

---

## 6. Passive placement

| Part | Qty | Where | Why |
|---|---|---|---|
| 100 µF 16 V | 2–3 | 5 V rail output; one at servo | bulk smoothing ⚠️ **never on motor bus** |
| 100 nF 50 V | 6–10 | at every IC supply pin | high-frequency decoupling |
| 60.4 Ω | 4 | 2 per CAN end | split termination |
| 4.7 nF | 2 | 1 per CAN end, midpoint→GND | common-mode shunt |
| 1N5819 | 1–2 | 5 V rail / servo | reverse polarity, flyback |
| **≥50 V bulk** | 1 | **motor bus** | **regen absorption — TO SOURCE** |

Decoupling caps go **as close to the pin as physically possible** — a 100 nF 10 mm away does much less than one at 2 mm.

---

## 7. Grounding — the star

The moteus drivers switch tens of amps. If that return current flows through signal ground, it injects noise into the IMU and CAN, and the symptom is an estimator that works on the bench and fails on the cube.

```
Battery −  ──►  POWER GROUND BUS   (heavy copper / thick wire on perfboard)
                  ├── moteus #1 GND   (short, direct)
                  ├── moteus #2 GND
                  ├── moteus #3 GND
                  ├── bulk capacitor −
                  └── LM2596 input −
                          │
                    ═══ ONE LINK ═══   ← the ONLY connection
                          │
                SIGNAL GROUND ──┬── Teensy GND
                                ├── BMI270 GND
                                ├── ESP32 GND
                                ├── CAN transceiver GND
                                ├── CAN bus GND (to all moteus)
                                └── servo GND
```

Rules:
- **One** connection between power and signal ground, near the LM2596.
- Never daisy-chain signal grounds through a driver.
- CAN GND is part of the signal ground — it is the shared reference for the differential pair.
- On the perfboard, run a wide ground trace or a copper strip; do not rely on thin jumpers.

---

## 8. KiCad resources

### 8.1 Where to get symbols, footprints, 3D models

| Source | Covers | Notes |
|---|---|---|
| **SnapMagic Search** (was SnapEDA) — snapeda.com | Teensy 4.1, most parts | Free, KiCad export incl. 3D |
| **ComponentSearchEngine** (SamacSys) | Teensy 4.1, generic parts | Free with account; symbol + footprint + 3D |
| **github.com/Seeed-Studio/OPL_Kicad_Library** | **XIAO ESP32-C6** (SMD + DIP) | Official Seeed; see gotcha below |
| **github.com/sparkfun/SparkFun-KiCad-Libraries** | SparkFun breakouts incl. BMI270 | Official; symbols + footprints + open 3D models |
| **github.com/XenGi/teensy_library** + **teensy.pretty** | Teensy symbols / footprints | Community, KiCad-native |
| **KiCad built-in libraries** | R, C, D, connectors, headers | Already installed |

### 8.2 ⚠️ The XIAO footprint gotcha

Seeed's repo ships **standalone `.kicad_mod` files** (`XIAO-ESP32C6-SMD.kicad_mod`, `XIAO-ESP32C6-DIP.kicad_mod`). KiCad 6/7/8/9 require footprints to live **inside a `.pretty` directory** to be recognised.

Fix: create a folder named e.g. `XIAO.pretty/`, move the `.kicad_mod` files into it, then add that folder via *Preferences → Manage Footprint Libraries*. Symbols come from `Seeed_Studio_XIAO_Series.kicad_sym` via *Manage Symbol Libraries*.

Use the **DIP variant** if socketing on headers (recommended — replaceable), SMD if soldering directly.

### 8.3 Parts with no ready-made library

**moteus-n1, MA600 breakout, LM2596 module, XT90/XT30** — likely need custom symbols. Since these are **modules that mount off-board or plug in**, the pragmatic approach for a perfboard build:

- Draw them as **generic connectors** in the schematic (e.g. `Conn_01x03` for a JST PH3, `Conn_01x02` for XT30) rather than full component symbols.
- The moteus is a separate board — represent it as a **connector block** with its power (XT30), CAN (PH3 in/out) and AUX2 (GH-7) pins.
- For 3D fit checking, grab STEP files where available: mjbots publishes mechanical drawings; XT connectors are on GrabCAD/Thingiverse.

For a **perfboard** build you don't strictly need footprints at all — the schematic is the deliverable, and the physical layout is hand-wired. Only invest in footprints if you move to a fabricated PCB.

### 8.4 Suggested schematic sheet structure

```
root.kicad_sch
 ├── 1_power.kicad_sch      battery, fuse, e-stop, bulk cap, LM2596, rails
 ├── 2_can.kicad_sch        transceiver, chain connectors, 2× termination
 ├── 3_compute.kicad_sch    Teensy, IMU, ESP32, servo, LED
 └── 4_drivers.kicad_sch    3× (XT30 + PH3 in/out + GH-7 encoder)
```

Use **global labels** for rails (`+5V`, `+3V3`, `VBAT`, `GND`, `GNDP`) and for `CANH` / `CANL`. Keeping power ground (`GNDP`) and signal ground (`GND`) as **separate nets joined at one symbol** makes the star grounding explicit in the schematic and prevents the layout tool from stitching them everywhere.

---

## 9. Bring-up sequence

Never power a new build from the battery. Use a **current-limited bench supply** set to ~1 A initially — the difference between a bug and a fire.

1. **Power only.** No modules fitted. Verify 5 V and 3.3 V rails, correct polarity, no shorts. Check LM2596 temperature.
2. **Teensy alone.** Blink. Confirm it enumerates over USB.
3. **IMU.** Read WHO_AM_I over SPI. Then stream raw gyro/accel.
4. **CAN, one driver.** Connect one moteus, confirm `tview` over the USB adapter sees it. Verify termination with a multimeter: **~60 Ω across CAN_H/CAN_L with power off** (two 120 Ω networks in parallel).
5. **Encoder.** Rotate the motor by hand, confirm a monotonic reading over a full revolution **with the wheel installed**.
6. **Torque mode.** Command a known torque, log acceleration — this is jig test M2 and confirms the whole architecture assumption.
7. **All three drivers.** Check bus utilisation and that arbitration is clean.
8. **Servo, ESP32** last — they are not on the critical path.

---

## 10. To verify before finalising the schematic

**Resolved:**
- ✅ CAN adapter is **CAN-FD at 5 Mbps** (TCAN330G) — confirmed from the product page
- ✅ Adapter has **120 Ω onboard termination**, cuttable trace → build only one split network
- ✅ Uses **CAN3, pins 30/31** — pin map confirmed
- ✅ Library: **FlexCAN_T4**

**Still open:**
- [ ] Does the **moteus-n1 have its own onboard termination**? If yes, reconsider the moteus #3 network.
- [ ] Does the **SparkFun BMI270 breakout expose SPI pins**? It is a Qwiic/I²C-first board.
- [ ] Exact **moteus PH3 pinout** (which pin is CANH / CANL / GND) — from mjbots docs, not assumed.
- [ ] Do the **30 cm PH3 cables have connectors both ends**, or one flying? Decides the §3.4 approach.
- [ ] **1N5819 intended role** — confirm with whoever specced it.
- [ ] Source: **≥50 V bulk capacitor**, **3× XT30 pairs**, **XT90-S anti-spark**, **inline fuse**.
- [ ] Confirm **moteus firmware ≥ 2024-10-29** for MA600 support.

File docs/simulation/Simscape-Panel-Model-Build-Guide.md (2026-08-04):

---
tags:
  - space-challenge
  - sofia
  - cubli
  - simscape
  - simulation
  - panel
  - controls
  - validation
  - cad
---

# Simscape Panel Model — Build Guide

Exact build procedure for the **Stage 1 planar panel** multibody model.
Companion to [[Panel Controller Workflow]] (which says *why*) and
[[Simulation Strategies]]. This note says *how*, block by block.

**Prerequisites**
- MATLAB + Simulink + Simscape + Simscape Multibody
- Simulink Control Design (needed for `linearize` in Gate 3)
- `cubli_panel_params.m` in `~/Documents/MATLAB/Space Challenge 2026/`
- The two STEP files, decompressed from `.stpZ` (they are gzip):
  `gunzip -c Static_Assembly_CORRECTED_AXES_A.stpZ > static.step`

**Estimated build time:** ~1 hour to a model that passes all six gates.

---

## 0 — The one decision that saves the most time

**Do NOT use `smimport`.**

Three reasons:
1. The `MN4006` arrives as **90 separate solids**. `smimport` generates a
   block for each. The model becomes unreadable and slow to compile.
2. `smimport` assigns **one density per imported body**. Both STEP files mix
   steel, plastic and motor. Any single density is wrong for most of the mass.
3. CATIA did not export materials at all, so there is nothing to inherit.

**Instead:** hand-build a **two-body** model. Use `File Solid` blocks with
**Inertia → Custom**, fed from `cubli_panel_params`. The STEP geometry then
drives *only* the rendering; the dynamics come from numbers you control and
can sweep. This is what makes the three retunes in [[Panel Controller Workflow]]
a one-line change.

> If the mesh looks 20 mm out of place in Mechanics Explorer, that is
> **cosmetic**. It cannot corrupt the plant. Do not spend time on it until
> the gates pass.

---

## 1 — Plant numbers

From the CATIA geometry, densities applied by part name
(steel 7850, motor 6793 kg/m³, plastic = `rho_plastic` argument).

| Quantity | Symbol | ρ = 1300 | ρ = 845 |
|---|---|---|---|
| Panel body mass (frame + motor) | `m_panel` | 0.3258 kg | 0.2532 kg |
| Wheel body mass | `m_wheel` | 0.1294 kg | 0.0940 kg |
| Total | | 0.4552 kg | 0.3472 kg |
| COM distance from pivot | $\ell$ | 100.41 mm | 100.92 mm |
| First moment | $S = m\ell$ | 0.04570 kg·m | 0.03504 kg·m |
| Second moment about pivot | $\Theta$ | 6.341e-3 kg·m² | 4.728e-3 kg·m² |
| Wheel inertia | $I_w$ | 3.581e-4 kg·m² | 2.789e-4 kg·m² |
| $\bar\Theta = \Theta - I_w$ | | 5.983e-3 | 4.449e-3 |
| $Sg$ | | 0.4484 N·m | 0.3437 N·m |
| Unstable pole | $\lambda$ | **8.657 rad/s** | **8.790 rad/s** |
| Free-swing period (hanging, wheel locked) | $T$ | **0.747 s** | **0.737 s** |

> [!important] $\lambda$ moves 2.9 % across a 2.2× density range
> $S$ and $\Theta$ both scale with mass, so the ratio that sets the time
> constant is nearly invariant — the same "mass cancels" result from the
> sizing notes. **Do not block the build on the density measurement.**
> Build at ρ = 845, pass the gates, then re-run with the measured value.

**Actuation ratios** (these are *not* invariant — see §6):

| ρ | $\tau_{cont}/Sg$ | $\theta_{static}$ cont | $\theta_{static}$ peak | $X = h_{max}^2/(2\Theta S g)$ |
|---|---|---|---|---|
| 1300 | 0.268 | 15.5° | 63.1° | 17.6 |
| 845 | 0.349 | 20.4° | **unbounded** | 18.7 |
| 700 | 0.387 | 22.7° | **unbounded** | 19.2 |

---

## 2 — Coordinate and sign conventions

Fix these **before placing a single block**. Every sign error downstream
traces back to skipping this section.

### World frame
- **+X** right, **+Y** up, **+Z** out of the panel plane, toward the viewer.
- Gravity: `Mechanism Configuration → Uniform Gravity = [0 -9.81 0]`.
- The panel plane is the **world XY plane**. Both rotation axes are **+Z**.

This choice is deliberate: Simscape's `Revolute Joint` always rotates about
the **Z axis of its base frame** (the `Rz` primitive). Putting the panel
normal on Z means **no rotation is needed on any Rigid Transform** — pure
translations only. Fewer places to get a sign wrong.

### Pivot location
The panel pivots about a **corner** of the 150 mm square, axis normal to the
panel plane. In the static STEP file the square spans 0…150 mm in x and y,
so the pivot corner is the **file origin (0, 0)** and the wheel axis is at
**(75, 75) mm**.

> [!warning] Verify this on the hardware
> If the pivot is actually at an **edge midpoint**, then $\ell$, $\Theta$ and
> the mount angle all change and this whole note needs rederiving.
> Check the bracket position on the built panel before trusting the numbers.

### Mount angle
At $\theta = 0$ the total COM must be **directly above the pivot**. The COM
sits at (70.98, 71.02) mm from the pivot corner — i.e. along the diagonal at
45.014°. So the panel geometry must be rotated by

$$\phi_{mount} = 90° - \operatorname{atan2}(c_y, c_x) = 44.986°$$

about Z to bring the diagonal vertical. This is **almost exactly 45°** and
almost density-independent (44.9863° at ρ=1300, 44.9876° at ρ=845), but
compute it rather than hard-coding it. Add to `cubli_panel_params.m`:

```matlab
p.phi_mount = pi/2 - atan2(p.com_total(2), p.com_total(1));   % rad
```

### State and torque signs
- $\theta$ = pivot joint position, **zero = upright**, positive = the
  direction of positive rotation about +Z.
- $\phi$ = wheel joint position **relative to the panel**.
- $u$ = torque commanded at the **wheel** joint.

$$\bar\Theta\,\ddot\theta = Sg\sin\theta - u, \qquad \dot h = u$$

> [!tip] Simscape gives you the reaction torque for free
> Actuating the wheel joint applies $+u$ to the follower (wheel) and $-u$ to
> the base (panel) automatically. **Do not add a reaction torque anywhere.**
> If you find yourself typing a minus sign to make the panel respond to the
> wheel, something upstream is wrong — go back and fix it, don't compensate.

---

## 3 — Block-by-block build

### 3.1 Skeleton

```
Solver Configuration ──┐
World Frame ───────────┤
  │                    │  (both connect to the same physical network)
  ├─ Rigid Transform  T_MOUNT      rotate +phi_mount about Z
  │    └─ Revolute Joint  PIVOT    q = theta
  │         └─ File Solid  PANEL_BODY
  │              └─ Rigid Transform  T_WHEEL   translate [0.075 0.075 z_w]
  │                   └─ Revolute Joint  WHEEL   q = phi, torque actuated
  │                        └─ File Solid  WHEEL_BODY
Mechanism Configuration (unconnected, sets gravity)
```

Two rigid bodies. Two joints. That is the entire mechanical model.

### 3.2 Block parameters — exact entries

**Solver Configuration** (Simscape → Utilities)
- Leave defaults for now. Local solver settings go in §7.

**Mechanism Configuration** (Simscape → Multibody → Utilities)
- Uniform Gravity: `Constant`
- Gravity: `[0 -9.81 0]`
- Linearization Delta: leave default

**World Frame** (Simscape → Multibody → Frames and Transforms)
- No parameters.

**Rigid Transform `T_MOUNT`**
- Rotation → Method: `Standard Axis`
- Axis: `+Z`, Angle: `p.phi_mount` , units `rad`
- Translation → Method: `None`

**Revolute Joint `PIVOT`** (Simscape → Multibody → Joints)
- **State Targets**
  - Position → Specify: ✅, Value `0`, Priority `High`
  - Velocity → Specify: ✅, Value `0`, Priority `High`
- **Internal Mechanics**
  - Equilibrium Position `0`, Spring Stiffness `0`
  - Damping Coefficient `0` ← **must be zero for Gates 3–5**
- **Limits** — leave off for now (added in §6)
- **Actuation**
  - Torque: `None`
  - Motion: `Automatically Computed`
- **Sensing**
  - Position ✅, Velocity ✅

**File Solid `PANEL_BODY`** (Simscape → Multibody → Body Elements)
- **Geometry**
  - File Type: `STEP`
  - File Name: path to the decompressed static STEP
  - Units: `mm`
- **Inertia**
  - Type: **`Custom`** ← the critical setting
  - Mass: `p.m_panel`
  - Center of Mass: `[p.com_panel(1) p.com_panel(2) 0]`
  - Moments of Inertia: `[p.Izz_panel_com/2 p.Izz_panel_com/2 p.Izz_panel_com]`
    - *(planar model — only Izz enters the dynamics; the in-plane terms are
      placeholders and never affect the result. Set them properly only if you
      later reuse this body in a 3D model.)*
  - Products of Inertia: `[0 0 0]`
- **Graphic** → Visual Properties → simple, colour to taste
- **Frames** → add a frame `W` at the wheel axis if you prefer that to a
  separate Rigid Transform (either works; the separate block is easier to read)

> The STEP file's own origin is the pivot corner, so the graphic lands
> correctly with no offset. The z extent (0…55 mm) will render the panel
> in front of the XY plane — harmless.

**Rigid Transform `T_WHEEL`**
- Rotation → Method: `None`
- Translation → Method: `Cartesian`
- Offset: `[0.075 0.075 p.z_wheel]` , units `m`
  - `p.z_wheel` is cosmetic. Pick whatever makes the render look right;
    it has **zero** effect on planar dynamics.

**Revolute Joint `WHEEL`**
- **State Targets**
  - Position → Specify: ✅, Value `0`, Priority `Low`
  - Velocity → Specify: ✅, Value `0`, Priority `High`
- **Internal Mechanics**
  - Damping Coefficient `0` ← zero for the gates, identified later (§6)
- **Actuation**
  - Torque: **`Provided by Input`**
  - Motion: `Automatically Computed`
- **Sensing**
  - Position ✅, Velocity ✅

**File Solid `WHEEL_BODY`**
- **Geometry**: the moving-assembly STEP, units `mm`
- **Inertia**
  - Type: `Custom`
  - Mass: `p.m_wheel`
  - Center of Mass: `[0 0 0]` (the wheel is balanced on its axis by design —
    the CAD confirms COM within 0.01 mm of the axis)
  - Moments of Inertia: `[p.Iw/2 p.Iw/2 p.Iw]`
  - Products of Inertia: `[0 0 0]`

### 3.3 Signal interfacing

- Torque input: **Simulink-PS Converter** into the `WHEEL` joint `t` port.
  Input Signal Unit: `N*m`. Filtering: `Filtering and derivatives` →
  **do not** leave this on `Provide input derivatives` unless you actually
  supply them; a first-order filter here will quietly add lag that shows up
  as a mysterious phase loss in Gate 3.
- All sensing ports: **PS-Simulink Converter**, units `rad` and `rad/s`.
- Bus the three states into one signal in the order **`[theta; theta_dot; phi_dot]`**
  to match the ETH convention and `cubli_lqr_design.m`.

### 3.4 Model callbacks

`Model Properties → Callbacks → InitFcn`:

```matlab
p = cubli_panel_params(845);     % measured rho goes here later
```

Everything in the block dialogs references `p.*`. One number changes,
the whole model follows.

---

## 4 — Validation gates

Same discipline as the eleven gates in `cubli_lqr_design.m`. **Nothing from
§6 goes in until all six pass.** Keep them as a script,
`cubli_panel_simscape_gates.m`, so they re-run after every change.

### Gate 1 — Hang test
Gravity on, zero torque, `WHEEL` joint temporarily **locked**
(set Actuation → Motion to `Provided by Input` with a constant 0).
Release from near-hanging.

**Pass:** the panel settles with the total COM directly *below* the pivot,
i.e. $\theta \to 180°$.
**Catches:** wrong gravity direction, wrong mount angle, COM entered in the
wrong frame. Takes 30 seconds and catches the most embarrassing errors.

### Gate 2 — Free-swing period
Small oscillation about hanging, wheel locked, zero damping.

$$T = 2\pi\sqrt{\Theta/(Sg)} = 0.747\ \text{s}\ (\rho{=}1300),\quad 0.737\ \text{s}\ (\rho{=}845)$$

**Pass:** simulated period within 0.5 % of analytic.
**Why this gate matters most:** it is the **same measurement you make on the
built panel** — a stopwatch and a phone camera. That makes it a three-way
check: analytic ↔ Simscape ↔ hardware. It is also how you obtain measured
$\Theta$ for the deployment gains in Step 4 of [[Panel Controller Workflow]].

### Gate 3 — Linearisation gate ★
The definitive one. Upright with zero torque **is** an exact equilibrium
(unstable, but exact), so **no trimming is needed** — linearise at `t = 0`
with the state targets already at zero.

```matlab
mdl = 'cubli_panel';
io(1) = linio([mdl '/TorqueIn'],  1, 'openinput');
io(2) = linio([mdl '/StateOut'],  1, 'openoutput');
sys   = linearize(mdl, 0, io);
[Aq, Bq] = ssdata(sys);

fprintf('A err: %.3e\n', norm(Aq - p.A)/norm(p.A));
fprintf('B err: %.3e\n', norm(Bq - p.B)/norm(p.B));
assert(norm(Aq - p.A)/norm(p.A) < 1e-6, 'A mismatch')
assert(norm(Bq - p.B)/norm(p.B) < 1e-6, 'B mismatch')
```

**Pass:** relative error < 1e-6.
If it passes, the multibody model and the LQR design script are **provably
the same plant**, and every gain from `lqr()` is valid in the sim.

**Reading the failure pattern:**

| Symptom | Cause |
|---|---|
| `A(2,1)` off by a scale factor | $S$ or $\bar\Theta$ wrong → check `m_panel`, `com_panel` |
| `B(3)` off | $I_w$ wrong → check `Custom` inertia actually took, not `Calculate from Geometry` |
| `B(2)` sign flipped | reaction torque convention → you added a manual reaction somewhere |
| `A(3,1)` ≠ `-A(2,1)` | the two bodies are not sharing one pivot correctly |
| Everything ~0 | linearisation I/O points not on the right lines |

### Gate 4 — Pole match
```matlab
eig(Aq)   % expect  +8.657, -8.657, 0   (rho = 1300)
```
Mirrors Gate 1 of `cubli_lqr_design.m`, now on the multibody model.

### Gate 5 — Energy conservation
Damping zero, torque zero, release from $\theta_0 = 20°$.
Total mechanical energy constant to solver tolerance (< 0.1 % drift over 10 s
on `ode23t` with `RelTol = 1e-8`).
**Catches:** inertia errors that Gates 3–4 can miss if two compensating
mistakes were made.

### Gate 6 — Momentum coupling
Gravity **off**, pivot free, torque impulse on the wheel.

**Pass:** angular momentum about the pivot stays zero —
$$\bar\Theta\,\Delta\dot\theta = -I_w\,\Delta\dot\phi$$

Isolates the coupling term, which is precisely what control authority
depends on. A model can pass Gates 1–5 and still have the coupling scaled
wrong if the wheel body is attached to the wrong frame.

---

## 5 — Gate checklist

- [x] Gate 1 — hang test settles COM below pivot
- [x] Gate 2 — period within 0.5 % of $2\pi\sqrt{\Theta/Sg}$
- [x] Gate 3 — `norm(Aq-p.A)/norm(p.A) < 1e-6` and same for B
- [x] Gate 4 — poles $\{+\lambda, -\lambda, 0\}$
- [x] Gate 5 — energy drift < 0.1 % over 10 s
- [x] Gate 6 — $\bar\Theta\Delta\dot\theta + I_w\Delta\dot\phi = 0$

---

## 6 — The nonlinear layer

This is what Simscape is **for** — see "What Simscape validates that MATLAB
can't" in [[Panel Controller Workflow]]. Add in this order. After each
addition, **disable it and re-run Gate 3** to confirm you haven't changed
the underlying plant.

### 6.1 Torque saturation
Saturation block on the torque command: `[-p.tau_cont, +p.tau_cont]`,
with a separate peak branch at `p.tau_peak` if you model a duty limit.
The panel is genuinely torque-limited (15.5° static at ρ=1300), so this
bites and is worth modelling honestly.

### 6.2 Wheel speed cap — **mandatory, not optional**
As built, $X = 17.6$: the panel could recover from beyond 180° on momentum
alone, and balancing at 10° uses **2.9 % of $h_{max}$**. It is impossible to
provoke momentum saturation. Worse, below ρ ≈ 900 the *peak* torque exceeds
$mg\ell$ and the static torque bound disappears too — the panel becomes
over-actuated in **both** channels, exactly the failure mode flagged in the
sizing notes.

So cap both, in **sim and firmware, from the same struct**:

| Cap | Value | Resulting bound |
|---|---|---|
| `p.omega_cap` | 40 rad/s | $X_{cap} \approx 0.038$ → ~15.9° |
| torque limit | 0.10–0.12 N·m (moteus current limit) | ~20° static |

$X_{cap}$ moves only 0.036 → 0.039 across the whole density range, so this
cap is safe to fix now and never revisit.

> Without these caps the saturation gate is testing an envelope the hardware
> will never see, and the classic "balances 8 seconds then falls" failure
> (see [[Disturbance Estimation & Attitude Representation]]) cannot be
> reproduced in simulation before you meet it on the bench.

### 6.3 Encoder quantisation
Quantizer blocks on both joint positions, LSB `p.enc_lsb = 2*pi/2^16`
(MA600, 65536 cpr). Then **differentiate the quantised signal** to get rate —
do not sense velocity directly from the joint. The derivative noise this
produces is real and is what forces the filter design.

### 6.4 Sample-and-hold and computational delay
Zero-Order Hold at `p.f_outer`, plus **one sample of delay**.
Do not skip the delay. It is the difference between margins that survive
deployment and margins that don't, and it is invisible in the continuous
design. See [[Simulation Strategies]] on loop-rate selection — remember the
binding constraint is anti-aliasing the ~141 Hz wheel fundamental, not
control bandwidth.

### 6.5 IMU model
Mount a **Transform Sensor** at the *actual* IMU body-frame position on the
panel — **not** at the pivot. Output **specific force**, not tilt angle.

This is the single most valuable thing the panel sim does: a lever arm $r$
from the pivot injects an $\dot\omega \times r$ error that is worst exactly
during recovery, when you most need the estimate. Record the IMU's
body-frame position from CAD, feed the complementary filter the raw
accelerometer and gyro signals, and let the filter deal with it.

Add: accelerometer noise, gyro noise, gyro bias random walk.

### 6.6 Friction
- `PIVOT`: viscous + Coulomb
- `WHEEL`: viscous + cogging torque ripple (12 pole pairs → 24 cycles/rev)

Leave the coefficients as parameters. Identify them from a **spin-down test**
on the real wheel and a **decay-envelope fit** on the free-swing test from
Gate 2 — both are measurements you're doing anyway.

### 6.7 Hard stops
`PIVOT` joint → **Limits** → lower and upper bound matching the **grey rails
on the base plate**. Those rails define the safe test envelope. Having them
in the model means aggressive tuning runs terminate meaningfully instead of
producing nonsense trajectories.

---

## 7 — Solver and performance

| Setting | Development | Controller-in-the-loop |
|---|---|---|
| Solver | `ode23t`, variable step | `ode4`, fixed step `1e-4` |
| RelTol | `1e-8` (needed for Gate 5) | n/a |
| Simscape local solver | off | consider `Backward Euler`, `1e-4` |

- Fixed-step `ode4` at 1e-4 is the honest test: it tells you whether the
  **discrete** implementation works, not just the continuous design.
- For batch runs (ρ sweeps, ±30 % robustness, gain sweeps) disable
  visualisation — typically a 5–10× speedup:
  ```matlab
  set_param(mdl, 'SimMechanicsOpenEditorOnUpdate', 'off');
  ```
- Lower the `File Solid` graphic tessellation. The motor's 90 solids will
  make Mechanics Explorer crawl and contribute **nothing**, since inertia
  is `Custom`.
- Use `parsim` for the robustness sweep once the gates pass.

---

## 8 — Retune hooks

The three retunes from [[Panel Controller Workflow]] are all one line here:

| Retune | Action |
|---|---|
| 1. Estimate | `p = cubli_panel_params(845);` |
| 2. CAD / measured density | `p = cubli_panel_params(rho_measured);` |
| 3. Measured $\Theta$ | override `p.Theta` from the Gate 2 period on hardware, recompute `p.A`, `p.B` |

After each: re-run Gate 3, then `lqr()`. The gains will barely move —
$\lambda$ shifts under 3 % across the plausible density range — but the
**actuation ratios** in §6.2 will, so re-check the caps.

---

## 9 — Open items

- [ ] **Confirm the pivot is at a corner, not an edge midpoint.** Everything
      in §2 assumes the corner. Measure the bracket on the built panel.
- [ ] **Measure $\rho_{eff}$.** 15 % infill is *not* a 0.15 density factor —
      perimeters and top/bottom layers dominate on a ribbed structure, so
      expect 40–60 % of nominal. Fastest routes: read the slicer's estimated
      filament mass per part, or weigh the assembled panel and invert:
      $$\rho_{eff} = (M_{measured} - 0.14656)/2.3740\times10^{-4}$$
      (fixed steel + motor mass 146.56 g; total plastic volume 237.40 cm³)
- [ ] **Motor rotor/stator split.** The `Moving Assembly` wraps the whole
      MN4006 with no split, and this model lumps all 90 solids into the panel
      body. The bell and magnets really do spin — worth about **+2–3 % on
      $I_w$**. Ask Andrea for the bell solid names if we want it exact; it
      sits below the plastic-density uncertainty either way.
- [ ] **IMU body-frame position** — needed from CAD for §6.5.
- [ ] Identify friction coefficients from spin-down and swing-decay tests.

---

## Related

- [[Panel Controller Workflow]] — why this model exists, and the retune order
- [[Simulation Strategies]] — what Simscape does and does not reproduce
- [[Disturbance Estimation & Attitude Representation]] — why $Q_h$ is 1–10
  and why a constant disturbance can't be cancelled
- [[References]]

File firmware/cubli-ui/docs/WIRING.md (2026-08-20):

# Wiring and hardware setup

Two boards, one cable pair, one ground. Edge and corner balance are the same
firmware on the same hardware — nothing here changes when you switch mode.

---

## Teensy 4.1 ↔ XIAO ESP32-C6

| Teensy 4.1 | direction | XIAO ESP32-C6 |
|---|---|---|
| **TX1** — pin 1 | → | **D7** (RX) |
| **RX1** — pin 0 | ← | **D6** (TX) |
| **GND** | — | **GND** |

**Crossed, not straight.** TX goes to RX on the other board.

A common ground is mandatory. Without it the link looks dead or produces garbage characters.

```
   TEENSY 4.1                      XIAO ESP32-C6
   ┌──────────┐                    ┌──────────┐
   │  pin 1 TX├───────────────────►┤D7 RX     │
   │  pin 0 RX│◄───────────────────┤D6 TX     │
   │      GND ├────────────────────┤ GND      │
   └──────────┘                    └──────────┘
```

---

## Link speed

```
1 000 000 baud   (1 Mbaud)
```

This value appears in **two** places and they must match:

| File | Constant |
|---|---|
| `xiao/xiao_teensy_bridge/xiao_teensy_bridge.ino` | `TEENSY_LINK_BAUD` |
| `teensy/CubliBalance/CubliBalance.ino` | `kLinkBaud` |

**A mismatch is silent.** The symptom looks exactly like a dead cable: no telemetry, a dead link pill.

### Why not 115200?

Corner mode sends ~200 bytes per line at 250 Hz ≈ 400 kbit/s. That does not fit in 115200. Writes would block inside the 2 ms control loop and the balance would fail.

The real ceiling is not the UART, though — it is the UDP hop, measured at ~105 lines/s in the link bring-up. Use `d<N>` if you need a readable rate rather than a captured one.

---

## Motors (moteus over CAN)

| Controller ID | Body axis |
|---|---|
| 2 | X |
| 3 | Y |
| 1 | Z |

CAN bus: **CAN3**, FD, 1 Mbit.

**Corner mode drives all three. Edge mode drives one** — `gEdgeAxis`, which
defaults to **Y (id 3)**. On every mode entry the firmware `SetStop()`s all
three, so in edge mode the other two are explicitly stopped rather than left to
time out on their own watchdogs.

---

## IMU

BMI270 over SPI, chip select on **pin 10**, 4 MHz.

---

## Power

- Battery: **6S** pack (25.2 V full, 22.2 V nominal, **18.0 V floor**)
- Below 18 V, stop and recharge.
- The XIAO can run from USB during bench work, but for untethered runs it must be powered from the cube.

---

## Wi-Fi

| Setting | Default |
|---|---|
| SSID | `cubli1` |
| XIAO IP | `172.20.10.14` |
| Gateway | `172.20.10.1` |
| Subnet | `255.255.255.240` |

These match an **iPhone hotspot**, which hands out a `/28` (`172.20.10.1` … `.14`).

If you use a different network, edit the IP block in the XIAO sketch, or switch it to DHCP and read the address from the USB serial monitor at boot.

---

## Before every session

- [ ] TX/RX crossed, GND shared
- [ ] Battery above 18 V
- [ ] Hotspot on, XIAO joined
- [ ] Clear space around the cube
- [ ] E-STOP reachable (browser open, or spacebar)
- [ ] Cube on a flat, stable surface
- [ ] **Right mode staged** (`m0` edge / `m1` corner) and the pivot re-resolved
- [ ] **Cube placed near equilibrium** — corner mode will arm at any tilt

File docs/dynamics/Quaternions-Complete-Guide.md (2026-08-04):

---
tags: [quaternions, attitude, math, robotics, cubli]
---

# Quaternions — Complete Guide for Attitude Representation

Written for someone who knows rotation matrices and Euler angles from a robotics course but never worked with quaternions properly. Goal: everything needed to (a) follow the [[3D Cubli Lagrangian Derivation]], (b) implement attitude kinematics in MATLAB/Simulink correctly, (c) not fall into the classic traps. Ordered from algebra → geometry → kinematics → practice.

---

## 1. What a quaternion is

A quaternion is a 4-component object
$$q = q_0 + q_1 i + q_2 j + q_3 k \;\equiv\; (q_0, \boldsymbol q_v), \qquad q_0 \in \mathbb R \text{ (scalar part)},\; \boldsymbol q_v = (q_1, q_2, q_3)^\top \in \mathbb R^3 \text{ (vector part)},$$
where the imaginary units satisfy Hamilton's relations:
$$i^2 = j^2 = k^2 = ijk = -1,$$
which imply $ij = k$, $jk = i$, $ki = j$, and **anti-commutativity**: $ji = -k$, etc.

Think of quaternions as the 4D generalization of complex numbers. And that analogy is not decorative — it's the whole point:

> **Unit complex numbers $e^{i\theta}$ represent rotations in 2D. Unit quaternions represent rotations in 3D.**

This is exactly why Ribas Martins & da Silva derive the 1D Cubli with unit complex numbers first, then the 3D Cubli with quaternions: same machinery, one dimension up.

---

## 2. Algebra you actually need

### 2.1 Quaternion product

For $q = (q_0, \boldsymbol q_v)$ and $p = (p_0, \boldsymbol p_v)$, expanding Hamilton's relations gives the compact vector form worth memorizing:
$$\boxed{\;q \otimes p = \big(q_0 p_0 - \boldsymbol q_v^\top \boldsymbol p_v,\;\; q_0\boldsymbol p_v + p_0 \boldsymbol q_v + \boldsymbol q_v \times \boldsymbol p_v\big)\;}$$

Key properties:
- **Not commutative**: $q\otimes p \neq p\otimes q$ in general (the $\times$ term flips sign). This is a feature, not a bug — 3D rotations don't commute either, and the quaternion product inherits exactly that non-commutativity.
- Associative: $(q\otimes p)\otimes r = q\otimes(p\otimes r)$. ✓
- Bilinear in both arguments.

Matrix form (useful for Jacobians and Simulink implementation): $q\otimes p = [q]_L\, p = [p]_R\, q$ where
$$[q]_L = \begin{bmatrix} q_0 & -\boldsymbol q_v^\top \\ \boldsymbol q_v & q_0\mathbb 1 + \hat{\boldsymbol q}_v \end{bmatrix}, \qquad
[p]_R = \begin{bmatrix} p_0 & -\boldsymbol p_v^\top \\ \boldsymbol p_v & p_0\mathbb 1 - \hat{\boldsymbol p}_v \end{bmatrix},$$
with $\hat{(\cdot)}$ the skew map. Note the sign flip on the skew term between left and right matrices.

### 2.2 Conjugate, norm, inverse

$$q^* = (q_0, -\boldsymbol q_v), \qquad \|q\|^2 = q\otimes q^* = q_0^2 + \|\boldsymbol q_v\|^2, \qquad q^{-1} = \frac{q^*}{\|q\|^2}.$$

For a **unit quaternion** ($\|q\| = 1$): $q^{-1} = q^*$ — inversion is free. This is one reason quaternions beat rotation matrices computationally (matrix inverse = transpose is also free, but quaternion storage is 4 numbers vs 9, and renormalization is cheaper than re-orthogonalization).

### 2.3 Pure quaternions

A quaternion with zero scalar part, $v = (0, \boldsymbol v)$, is called **pure** and is how we embed 3D vectors into quaternion algebra. Products of pure quaternions encode both dot and cross product at once:
$$(0,\boldsymbol a)\otimes(0,\boldsymbol b) = (-\boldsymbol a^\top\boldsymbol b,\; \boldsymbol a\times\boldsymbol b).$$

---

## 3. Unit quaternions as rotations

### 3.1 The axis–angle connection

Any 3D rotation is a rotation by angle $\theta$ about a unit axis $\boldsymbol n$ (Euler's theorem). The corresponding unit quaternion is
$$\boxed{\;q = \Big(\cos\tfrac\theta2,\; \boldsymbol n\sin\tfrac\theta2\Big)\;}$$

**The half angle is not a typo.** It's the single most important structural fact about quaternions, and the reason for both their power and their one quirk (double cover, §3.4). Compare with 2D: $e^{i\theta}$ rotates by $\theta$; the quaternion "lives on" $\theta/2$ because a vector gets sandwiched between $q$ and $q^*$, picking up the rotation twice.

Sanity checks:
- $\theta = 0$: $q = (1, \boldsymbol 0)$ — the identity quaternion. ✓
- $\theta = 180°$ about $z$: $q = (0, 0, 0, 1)$ — a pure quaternion. ✓

### 3.2 Rotating a vector

To rotate vector $\boldsymbol v$ by the rotation encoded in unit quaternion $q$:
$$\boxed{\;(0, \boldsymbol v') = q \otimes (0, \boldsymbol v) \otimes q^*\;}$$
The result is automatically pure (the scalar part cancels — worth verifying once by hand). Expanding gives the rotation-matrix equivalent:
$$\boldsymbol v' = R(q)\,\boldsymbol v, \qquad R(q) = (q_0^2 - \boldsymbol q_v^\top\boldsymbol q_v)\,\mathbb 1 + 2\,\boldsymbol q_v\boldsymbol q_v^\top + 2 q_0\,\hat{\boldsymbol q}_v.$$

Written out (the form you'll type into MATLAB exactly once and then wrap in a function):
$$R(q) = \begin{bmatrix}
1-2(q_2^2+q_3^2) & 2(q_1q_2 - q_0q_3) & 2(q_1q_3 + q_0q_2)\\
2(q_1q_2 + q_0q_3) & 1-2(q_1^2+q_3^2) & 2(q_2q_3 - q_0q_1)\\
2(q_1q_3 - q_0q_2) & 2(q_2q_3 + q_0q_1) & 1-2(q_1^2+q_2^2)
\end{bmatrix}$$

### 3.3 Composition

Rotating first by $q_1$ then by $q_2$ composes as
$$q_{\mathrm{total}} = q_2 \otimes q_1$$
(same order convention as rotation matrices, $R_2 R_1$). Verify: $q_2\otimes(q_1\otimes v\otimes q_1^*)\otimes q_2^* = (q_2\otimes q_1)\otimes v\otimes(q_2\otimes q_1)^*$, using $(q_2\otimes q_1)^* = q_1^*\otimes q_2^*$.

### 3.4 The double cover — $q$ and $-q$ are the same rotation

From the half-angle formula: replacing $\theta \to \theta + 2\pi$ gives $q \to -q$ but obviously the same physical rotation. So:
$$R(q) = R(-q).$$
The unit quaternions form the 3-sphere $S^3$, which wraps around the rotation group $SO(3)$ **twice** ("double cover").

Practical consequences:
1. **Attitude checks:** "is the attitude close to target?" must test $|q_0^{\mathrm{err}}|\approx 1$, not $q^{\mathrm{err}} \approx (1,\boldsymbol 0)$ — the error could legitimately be near $(-1, \boldsymbol 0)$.
2. **The unwinding problem in control:** naive quaternion feedback can drive the attitude the *long way around* (359° instead of −1°) when $q_0^{\mathrm{err}} < 0$. Standard fix: multiply the feedback by $\mathrm{sign}(q_0^{\mathrm{err}})$. For Cubli corner balancing you stay near one equilibrium so it rarely bites, but the check costs one line — include it.
3. **Interpolation/filtering/averaging:** before combining two quaternions, flip the sign of one if their dot product is negative.

### 3.5 Why not Euler angles?

You know this from the robotics course but it's worth making crisp, because it's *the* justification for the quaternion overhead:

| | Euler angles | Rotation matrix | Quaternion |
|---|---|---|---|
| Parameters | 3 | 9 | 4 |
| Constraints | 0 | 6 (orthonormality) | 1 (unit norm) |
| Singularities | **Yes — gimbal lock** | No | **No** |
| Composition cost | trig-heavy | 27 mult | 16 mult |
| Renormalization | — | Gram–Schmidt (awkward) | divide by norm (trivial) |
| Interpolation | poor | poor | SLERP (clean) |

Gimbal lock is not a numerical nuisance, it's a topological fact: no 3-parameter chart covers $SO(3)$ without singularities. For the Cubli, the corner-balancing equilibrium can be *placed* away from any given Euler singularity, so Euler angles would *work* — but the 3D derivation becomes a trigonometric swamp, and any large-angle maneuver (jump-up!) risks passing near the singularity. Quaternions cost one extra state and one norm constraint, and buy global, singularity-free, trig-free dynamics. That trade is why ECC 2013, TCST 2016, Ribas Martins, and every modern satellite ADCS (including what you'd fly on ASTERIA) use quaternions.

---

## 4. Kinematics — the equation that matters for the Cubli

### 4.1 Derivation of $\dot q$

Let $q(t)$ be the attitude (body→inertial) and $\boldsymbol\omega$ the angular velocity **in the body frame**. Over a small time $dt$ the body rotates by axis $\boldsymbol\omega/\|\boldsymbol\omega\|$, angle $\|\boldsymbol\omega\|dt$, so with the half-angle formula the increment quaternion is, to first order,
$$dq = \Big(1, \tfrac12\boldsymbol\omega\,dt\Big).$$
Since the increment is expressed in the **body** frame, it composes on the **right**:
$$q(t+dt) = q(t)\otimes dq \;\Rightarrow\; \boxed{\;\dot q = \tfrac12\, q\otimes(0,\boldsymbol\omega)\;}$$

This is the equation in §3 of the [[3D Cubli Lagrangian Derivation]]. If $\boldsymbol\omega$ were expressed in the inertial frame, it would compose on the left: $\dot q = \tfrac12 (0,\boldsymbol\omega_I)\otimes q$. **Getting body-vs-inertial and left-vs-right consistent is the #1 source of sign bugs in attitude code.** Pick one convention (body-frame $\boldsymbol\omega$, right multiplication — matches our Cubli note and most robotics literature) and never mix.

In matrix form for implementation:
$$\dot q = \tfrac12\,\Omega(\boldsymbol\omega)\,q, \qquad \Omega(\boldsymbol\omega) = \begin{bmatrix} 0 & -\boldsymbol\omega^\top \\ \boldsymbol\omega & -\hat{\boldsymbol\omega} \end{bmatrix}.$$

### 4.2 Norm preservation and numerical integration

Analytically, $\frac{d}{dt}\|q\|^2 = 2q^\top\dot q = q^\top\Omega q = 0$ ($\Omega$ is skew-symmetric) — the kinematics preserve the unit norm exactly. Numerical integrators do **not**: `ode45` will let $\|q\|$ drift.

Handling, from crude to correct:
1. **Brute-force renormalization** $q \leftarrow q/\|q\|$ every step (or at each filter update). Fine for simulation; what almost everyone does.
2. **Exact discrete propagation** for constant $\boldsymbol\omega$ over a step $\Delta t$:
$$q_{k+1} = q_k \otimes \Big(\cos\tfrac{\|\boldsymbol\omega\|\Delta t}{2},\; \tfrac{\boldsymbol\omega}{\|\boldsymbol\omega\|}\sin\tfrac{\|\boldsymbol\omega\|\Delta t}{2}\Big).$$
Norm-preserving by construction; the right choice inside a fixed-step Simulink attitude propagator or an onboard filter.
3. In Simscape Multibody you don't integrate $q$ yourself — the engine handles it — but the analytical model you validate against does, so use 1 or 2 there.

**Simulation health check** (already in the Cubli validation checklist): $|\,\|q\|-1\,| < 10^{-6}$ throughout; tighten `RelTol/AbsTol` if violated.

### 4.3 Attitude error quaternion

For control you need "how far is current attitude $q$ from desired $q_d$":
$$q_{\mathrm{err}} = q_d^{*}\otimes q = (q_{e0}, \boldsymbol q_{ev}).$$
For small errors, $q_{e0}\approx 1$ and $\boldsymbol q_{ev} \approx \tfrac12\,\boldsymbol\delta$ where $\boldsymbol\delta$ is the small rotation vector — so **$2\boldsymbol q_{ev}$ is the attitude error "vector"** you feed to a linear controller. (Factor of 2 again from the half angle. Forgetting it just rescales your gains, but be consistent.)

This is why the linearized Cubli model can use a 3-component attitude perturbation: near equilibrium, the quaternion vector part *is* (half) the small rotation vector. The reduced $\boldsymbol g_B$ formulation in the Cubli note sidesteps quaternions for the same small-signal purpose — the two views are consistent.

### 4.4 Relationship to the $\boldsymbol g_B$ trick

In the Cubli derivation we propagate $\dot{\boldsymbol g}_B = \boldsymbol g_B\times\boldsymbol\omega$ instead of (or alongside) $\dot q$. Connection: $\boldsymbol g_B = -g\,R(q)^\top \boldsymbol e_z$ — $\boldsymbol g_B$ is the part of the attitude that gravity can "see." It loses yaw (rotation about vertical) but needs no normalization beyond $\|\boldsymbol g_B\| = g$ and gives the smallest possible state for balancing control. Full quaternion: keep when you care about full attitude (jump-up, yaw regulation, Simscape ground truth). $\boldsymbol g_B$: enough for pure corner balancing.

---

## 5. Conversions (implement once, unit-test, trust forever)

### Quaternion → rotation matrix
Given in §3.2. MATLAB: `quat2rotm` — but **check its convention** (MATLAB uses $q = [w\,x\,y\,z]$ scalar-first, Hamilton convention, consistent with ours).

### Rotation matrix → quaternion (Shepperd's method)
Naive extraction $q_0 = \tfrac12\sqrt{1+\mathrm{tr}R}$ is numerically bad when $\mathrm{tr}R \to -1$ (rotations near 180°). Robust approach: compute all four candidate pivots $\big(1{+}\mathrm{tr}R,\; 1{+}2R_{11}{-}\mathrm{tr}R,\; \ldots\big)$, take the largest, recover the rest from off-diagonal sums/differences. `rotm2quat` does this internally — use it, but know why.

### Axis–angle ↔ quaternion
§3.1 forward; inverse: $\theta = 2\,\mathrm{atan2}(\|\boldsymbol q_v\|, q_0)$, $\boldsymbol n = \boldsymbol q_v/\|\boldsymbol q_v\|$ (undefined at $\theta = 0$; return any axis). Use `atan2`, never `acos` — better conditioning near 0 and π.

### Euler angles ↔ quaternion
Compose the three elemental quaternions in the chosen sequence, e.g. ZYX: $q = q_z(\psi)\otimes q_y(\theta)\otimes q_x(\phi)$ with $q_z(\psi) = (\cos\tfrac\psi2, 0,0,\sin\tfrac\psi2)$ etc. Only needed at interfaces (human-readable I/O, comparing against Euler-based results) — never inside the dynamics.

---

## 6. SLERP — interpolation (for trajectory generation)

To interpolate smoothly from $q_1$ to $q_2$ with parameter $s\in[0,1]$:
$$\mathrm{slerp}(q_1, q_2, s) = q_1\otimes\big(q_1^*\otimes q_2\big)^s, \qquad p^s \equiv \Big(\cos\tfrac{s\theta}2,\;\boldsymbol n\sin\tfrac{s\theta}2\Big)\text{ for } p = \big(\cos\tfrac\theta2, \boldsymbol n\sin\tfrac\theta2\big),$$
i.e. constant-angular-velocity motion along the geodesic. Remember the double-cover rule: if $q_1^\top q_2 < 0$, flip $q_2 \to -q_2$ first, or you'll interpolate the long way around. Relevant if we ever generate reference attitude trajectories (e.g. edge→corner transition profiles); not needed for pure stabilization.

---

## 7. Conventions — read before touching anyone else's code

Attitude code from different sources silently disagrees on four independent choices. Any mismatch = sign bugs that "almost work":

1. **Scalar first $(w,x,y,z)$ vs scalar last $(x,y,z,w)$.** MATLAB, Eigen: scalar first. ROS, SciPy, many game engines: scalar last.
2. **Hamilton ($ij = k$) vs JPL ($ij = -k$) convention.** Almost everything modern is Hamilton; older aerospace/JPL filter literature (including some Kalman filter papers you might read for IMU fusion!) is JPL. A JPL-convention formula pasted into Hamilton code flips the rotation direction.
3. **Active vs passive** (rotate the vector vs rotate the frame): $R$ vs $R^\top$.
4. **Body→inertial vs inertial→body** as "the" attitude quaternion.

**Our convention stack (matches [[3D Cubli Lagrangian Derivation]] and MATLAB):** Hamilton, scalar-first, $q$ maps body→inertial, $\boldsymbol\omega$ in body frame, kinematics $\dot q = \tfrac12 q\otimes(0,\boldsymbol\omega)$ (right multiplication). Write this at the top of every script.

---

## 8. Worked micro-examples (do these by hand once)

1. **90° about $z$ applied to $\boldsymbol e_x$:** $q = (\tfrac{\sqrt2}2, 0, 0, \tfrac{\sqrt2}2)$; compute $q\otimes(0,\boldsymbol e_x)\otimes q^*$ and verify you get $(0, \boldsymbol e_y)$.
2. **Non-commutativity:** 90° about $x$ then 90° about $z$, vs the reverse order. Compute both $q_z\otimes q_x$ and $q_x\otimes q_z$, convert to axis–angle, confirm they differ — and match what you get physically rotating a book.
3. **Double cover:** verify $R(q) = R(-q)$ by plugging $-q$ into the §3.2 matrix (every entry is quadratic in $q$ — that's the proof).
4. **Kinematics sanity:** constant $\boldsymbol\omega = (0,0,\omega_z)$, initial $q=(1,\boldsymbol 0)$: solve $\dot q = \tfrac12 q\otimes(0,\boldsymbol\omega)$ analytically → $q(t) = (\cos\tfrac{\omega_z t}2, 0,0,\sin\tfrac{\omega_z t}2)$. The half angle appearing in the solution = everything consistent.

---

## 9. Cheat sheet

$$
\begin{aligned}
&q\otimes p = (q_0p_0 - \boldsymbol q_v^\top\boldsymbol p_v,\; q_0\boldsymbol p_v + p_0\boldsymbol q_v + \boldsymbol q_v\times\boldsymbol p_v) && \text{product}\\
&q = (\cos\tfrac\theta2, \boldsymbol n\sin\tfrac\theta2) && \text{axis–angle}\\
&(0,\boldsymbol v') = q\otimes(0,\boldsymbol v)\otimes q^* && \text{rotate vector}\\
&q_{\mathrm{tot}} = q_2\otimes q_1 && \text{compose (1 then 2)}\\
&\dot q = \tfrac12\,q\otimes(0,\boldsymbol\omega_B) && \text{kinematics, body }\boldsymbol\omega\\
&q_{\mathrm{err}} = q_d^*\otimes q,\quad \text{error vec} \approx 2\boldsymbol q_{ev} && \text{control error}\\
&q \text{ and } -q: \text{same rotation} && \text{double cover}\\
&q^{-1} = q^* \text{ iff } \|q\|=1 && \text{cheap inverse}
\end{aligned}
$$

## Where this plugs into the project
- [[3D Cubli Lagrangian Derivation]] §3 uses $\dot q = \tfrac12 q\otimes(0,\boldsymbol\omega)$ and the $\boldsymbol g_B$ reduction (§4.4 here).
- The Kalman filter for IMU fusion will use the error-quaternion small-angle state (§4.3) — that's the "multiplicative EKF" structure, worth a dedicated note when we get there.
- ASTERIA ADCS uses the identical formalism — this note doubles as GNC reference material.

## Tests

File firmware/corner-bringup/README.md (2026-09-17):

# Corner Bring-Up — three wheels, one corner at a time

Staged Arduino IDE firmware for bringing the cube up to closed-loop corner
balance, all three wheels live at once, same staged shape as
[`edge-bringup`](../edge-bringup/README.md) and the panel's
`firmware/panel-bringup/Stage0-5` before it — see
[`Firmware Lessons — 2D Panel to 3D Cube.md`](../../docs/Firmware-Lessons-2D-Panel-to-3D-Cube.md)
§7 for why that progression is worth repeating "nearly unchanged" rather
than jumping straight to a closed loop.

Started once `cube-bringup`'s Stage0/0b/0c all passed with all three
wheels powered simultaneously (bench power supply, not the flight battery
yet) — this is the corner-balance follow-on `edge-bringup`'s own NOTES
pointed at once the other two wheels were live.

## Why this is a bigger jump than edge-bringup

Edge balance is single-wheel: one active wheel, a 3-state law
(`phi_edge`, `om_edge`, `rho_axis`), independent scalar gains. Corner
balance is genuinely coupled: **all three wheels contribute to every
wheel's torque command.** Each wheel's row of `cubli_gains.h`'s per-corner
`Kp[3][9]` dots against the FULL 9-state vector
`[phi(3); om(3); rho(3)]` — there is no independent per-axis gain to
tune one wheel at a time the way edge-bringup could. What IS still
per-axis: each wheel's `kWheelSign` (a wiring-convention fact, carried
forward from edge-bringup, all three already confirmed `+1.0f` there) and
which of the 8 corners is currently down (resolved by measurement, same
discipline as edge-bringup's per-axis candidate resolution, just 8-way
instead of 2-way).

## The state-masking trick

Rather than five files each carrying a DIFFERENT slice of `Kp` (risking a
transcription mismatch between them), every stage in this folder carries
the exact SAME `kCorners[8]` table, copy-paste identical. What changes
per stage is which entries of the 9-wide state vector `x` are zeroed
before the `Kp . x` dot product:

| Stage | phi (cols 0-2) | om (cols 3-5) | rho (cols 6-8) |
|---|---|---|---|
| 2 (Rate Only) | zero | live | zero |
| 3 (Position Damping) | live | live | zero |
| 4 (Full Law) | live | live | live |
| 5 (Release) | live | live | live |

Stage 1 has no closed loop at all (open-loop pulse only). This is the same
idea as edge-bringup's `K[0]=K[2]=0` in its scalar law, generalized to a
coupled matrix by masking the STATE instead of the GAIN.

## Files

| File | Motors move? | What it adds |
|---|---|---|
| `Stage1_CornerIDAndPulse/` | Yes — fixed pulse, one wheel at a time | Corner identification (8-way, by measurement); per-wheel pulse test re-confirms `kWheelSign` under the new state framing and that all three wheels commanded together (even with two at zero torque) behaves cleanly |
| `Stage2_RateOnly/` | Yes — closed loop | om block only, full safety scaffold introduced (single `gArmed` for all three wheels) |
| `Stage3_PositionDamping/` | Yes — closed loop | Adds phi block, gain ramped 0.1→1.0 by hand |
| `Stage4_FullLaw/` | Yes — closed loop | Adds rho block (momentum management), friction feedforward per wheel, real arm gate (0.5° on `norm3(phi)`) |
| `Stage5_Release/` | Yes — closed loop, unsupported | Real `DISARM` (15° on `norm3(phi)`) / `OMEGA_CAP` (40 rad/s per wheel) trip policy, latched trip-reason (now also names WHICH wheel tripped an omega limit), the actual balancing attempt |

## `cubli_gains.h` and the attitude doc are now real files

Both [`../cubli_gains.h`](../cubli-ui/teensy/cubli_gains.h) and
[`../Attitude representation for the firmware.md`](../../docs/dynamics/Attitude-Representation-for-Firmware.md)
are checked into the repo as of this folder — previously they were only
referenced by name in edge-bringup's comments. `cubli_gains.h` is the
single source of truth every stage file's literal `kCorners`/`kCandidates`
tables are copied from; if the plant/LQR design ever changes, regenerate
that file and re-copy the relevant table into each `.ino`, the same
manual-sync workflow edge-bringup already established (Arduino sketches in
this environment can't reliably `#include` a header outside their own
sketch folder — see `Firmware Lessons` on the IDE's sketchbook-resolution
quirks — so literal duplication per file is the deliberate, tested choice,
not an oversight).

## Which corner

`cubli_gains.h` has all 8 corners (`[±1,±1,±1]`), each with its own `gB`,
full `Kp[3][9]`, and `theta_eq` (lean vs. the body diagonal, comparable to
edge-bringup's `place_offset`):

| corner | lean (deg) | corner | lean (deg) |
|---|---|---|---|
| `[+1,+1,+1]` | 0.714 (best) | `[+1,-1,+1]` | 2.609 |
| `[-1,-1,-1]` | 0.797 | `[-1,+1,-1]` | 2.773 |
| `[-1,+1,+1]` | 3.097 | `[+1,+1,-1]` | 3.095 |
| `[+1,-1,-1]` | 3.171 | `[-1,-1,+1]` | 3.170 |

Every stage resolves which one is down **by measurement, not memory** —
at startup (and on the `c` serial command any time), it compares the
measured `ghat` against all 8 candidate `gB` vectors and picks whichever
one it actually agrees with best, printing the answer, the runner-up, and
a warning if the two are too close to call.

## Hardware status

**Corner balance works** — `[+1,+1,+1]` and `[-1,-1,-1]` both hold on real
hardware through Stage 4. Notably, these are exactly the body-diagonal
pair with the smallest predicted lean in the table above (0.714°/0.797°,
vs. 2.6–3.2° for the other six) — the corner that CAD/LQR design predicted
would be easiest to balance is the one that actually balances, on the
first pair tried. Real confirmation the design methodology tracks
hardware, not a coincidence.

The other six corners are **not** reachable on this build — not a control
law or firmware problem. At those orientations gravity leans the cube
such that one or more wheels contact the frame directly (mechanical
clearance, not electrical/software), before the control law ever gets a
chance to act. Fixing that is a CAD/mechanical question (frame clearance,
wheel/motor placement), out of scope for this folder. Two working corners
on the main space diagonal is enough to demonstrate closed-loop 3-wheel
corner balance — the goal this bring-up needed to hit.

`z1`/`z0` (tare the phi offset) and a loosened Stage 4 velocity cap (2000
RPM motor rating instead of the 40 rad/s policy value) were both needed
to arm and hold on the bench power supply — see `Stage4_FullLaw.ino`'s
header for the reasoning. Both are Stage-4-only; Stage 5 keeps the real
`DISARM`/`OMEGA_CAP` policy.

## What's still open

- **The other six corners are untested and may stay mechanically
  unreachable** on this build regardless of firmware — see Hardware
  status above. Re-check after any frame/mount changes.
- **Friction feedforward (`kTauCw`/`kBw`) is one placeholder pair shared
  across all three wheels** — plausible for three copies of the same
  motor/mount, but unverified; a real per-wheel spin-down test would
  confirm or correct it.
- **IMU calibration** is still the 2D panel's numbers, copied forward with
  the same TODO as `Gam/Skeleton_3Axis.ino` and `edge-bringup`.
- **`Gam/Skeleton_3Axis.ino`'s own estimator** still needs the LERP→kP/kI
  filter swap this folder (and edge-bringup) already carries — separate,
  not done by these files.
- **Still on the bench power supply, not the flight battery** — expect
  `Sg`/`lambda` (and therefore how well the current `Kp` performs) to be
  somewhat off from the final mass distribution; re-derive gains once the
  real battery/DC-DC are mounted, same measure→derive→re-tune workflow as
  everywhere else in this project. The phi-offset tare will need re-taring
  (or clearing with `z0`) once that mass moves the real equilibrium.

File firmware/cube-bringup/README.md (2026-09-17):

# Cube Bring-Up — Phase 0, gam build

Staged Arduino IDE firmware bringing the 3D cube's CAN and IMU links up to
the point where `Gam/Skeleton_3Axis.ino` can be trusted to run against real
hardware. Not part of the panel's Stage 0-5 progression — those tests were
about the control loop on one axis; these are about whether the three-wheel
CAN bus and the IMU can sustain the loop rate the control law will need,
before any estimator or gain is involved at all.

Driver commissioning (encoder offset, phase order, `v_per_hz`) is assumed
already done via `moteus_tool`/`tview` — none of this re-does that. This is
the application layer: our CAN traffic pattern, our `SetPosition` `Format`
contract, and clean timing on this specific cube's wiring.

## Files, in run order

| File | Tests | Pass criterion |
|---|---|---|
| `Stage0_SingleMoteusQuery/` | One wheel, query/reply/stop/zero-torque | 60 s, zero errors — **run 3x, once per wheel ID**, before Stage0b |
| `Stage0b_ThreeMoteusLatency/` | All 3 wheels, one 400 Hz loop, CAN contention | p99.9 round-trip < 2.0 ms, zero dropped cycles, 10 min |
| `Stage0c_IMUJitter/` | BMI270 at 800 Hz ODR, polled at 400 Hz | zero stale (repeated) samples over 60 s |
| `Stage0d_Simultaneous/` | All 3 wheels commanded to the same constant velocity together (cube resting free, not hand-held) | zero comms errors, each wheel's velocity converges to target, 25 s |

CAN and IMU are tested separately here on purpose — combining them is what
`Gam/Skeleton_3Axis.ino` already does, and isolating which subsystem is
responsible for a timing problem is the whole point of a staged bring-up
(see [`Firmware Lessons — 2D Panel to 3D Cube.md`](../../docs/Firmware-Lessons-2D-Panel-to-3D-Cube.md) §7).

## What's still open after these pass

- **`Stage0_SingleMoteusQuery`'s `kMoteusId`** must be changed and re-run
  for wheel IDs 2 and 3 — a clean link on one wheel says nothing about the
  other two, different CAN node and different physical wiring run.
- **`Stage0c`'s filter bandwidth (`bwp`)** is deliberately left at the
  library default. Picking the value that lands the cutoff near 100 Hz at
  800 Hz ODR, and reading off that setting's group delay, requires the
  BMI270 datasheet's filter response table — not something firmware
  behavior can determine on its own. TODO is in the file.
- **`kWheelSign[3]`** is not tested by any of these three files — that's
  Phase 1.3, isolated per-wheel pulse tests with the panel firmly held,
  same method as the panel's Stage 1. Do that before Phase 2.

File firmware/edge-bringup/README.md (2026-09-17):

# Edge Bring-Up — axis-selectable (X / Y / Z)

Staged Arduino IDE firmware for bringing the cube up to closed-loop edge
balance, one wheel at a time, same staged shape as the panel's
`firmware/panel-bringup/Stage0-5` — see
[`Firmware Lessons — 2D Panel to 3D Cube.md`](../../docs/Firmware-Lessons-2D-Panel-to-3D-Cube.md)
§7 for why that progression is worth repeating "nearly unchanged" rather
than jumping straight to a closed loop.

Started ahead of Phase 4 (corner) because edge only ever needs one moteus
powered — full corner balance needs all three wheels soldered to the
battery.

Every stage now carries an `enum Axis { AXIS_X, AXIS_Y, AXIS_Z }` and a
single `static const Axis kAxis = ...;` switch near the top (Objects and
Settings section). Change that one line, re-upload, and the whole file —
moteus CAN id, edge-candidate table, wheel sign, boot-time confirmation
print — follows automatically:

```cpp
enum Axis { AXIS_X = 0, AXIS_Y = 1, AXIS_Z = 2 };
static const Axis kAxis = AXIS_Y;   // <<< CHANGE THIS to test X or Z
```

Physically confirmed wheel/axis/CAN-id mapping (bench-verified, see
`Gam/Skeleton_3Axis.ino`'s mapping comment): **id 2 = X, id 3 = Y, id 1 = Z**.
`kAxisMoteusId[3] = { 2, 3, 1 }` encodes this once; nothing else in these
files should hardcode a moteus id.

## Files

| File | Motor can move? | What it adds |
|---|---|---|
| `Stage1_WheelSignCheck/` | Yes — fixed pulse only | First real torque command to the active wheel; determines that axis's `kWheelSign` and, as a side effect, which edge candidate (`[+1,+1]` vs `[-1,-1]`) is physically under the cube |
| `Stage2_RateOnly/` | Yes — closed loop | Rate feedback only (`K[1]`/`om_edge`), full safety scaffold introduced |
| `Stage3_PositionDamping/` | Yes — closed loop | Adds position feedback (`K[0]`/`phi_edge`), gain ramped 0.1→1.0 by hand |
| `Stage4_FullLaw/` | Yes — closed loop | Adds momentum management (`K[2]`), friction feedforward, the real arm gate (0.5°), live `kPhiOffset` (`o<deg>`), velocity cap removed for this stage only |
| `Stage5_Release/` | Yes — closed loop, unsupported | Real `DISARM`/`OMEGA_CAP` trip policy (velocity cap restored to 40 rad/s), latched trip-reason, the actual balancing attempt |

## Final builds

Once bring-up is done, the two builds you actually run live in
[`../edge-balance-final/`](../archive/edge-balance-final): a byte-identical copy of
`Stage4_FullLaw/` (USB) alongside `Stage4_FullLaw_WiFi/`, the same control law
with a Serial1→XIAO→WiFi/UDP telemetry+command link so the cube runs
untethered. That folder's README carries the end-to-end flashing procedure.

## What's genuinely new here, not copied from the panel

The panel's `atan2` estimator trick is 2D/45°-mount specific and does not
apply — the cube tips in a real 3D way even with only one wheel actuating.
Every stage carries the same reduced-attitude (`ghat`/`w_b`) estimator
`Gam/Skeleton_3Axis.ino` uses, projected onto the single active edge's
direction (`phi_edge`, `om_edge`), not a different filter per axis. Edge is
a 3-state *projection* of the same estimator the corner build uses, not a
separate one — swapping `kAxis` only changes which edge direction (`e`) and
`gB` pair that projection uses, not the estimator itself.

**One deliberate difference from `Gam/Skeleton_3Axis.ino` as it stands
today:** these files use the validated `kP=4`/`kI=0.5` cross-product
complementary filter from `Attitude representation for the firmware.md` /
`cubli_gains.h` directly. `Gam/Skeleton_3Axis.ino` still runs the LERP-blend
filter that was flagged as needing replacement before any real closed loop
(it's past the measured `kP` cliff, just never triggered there because
`commandWheels()` is a zero-torque stub). Edge balance *is* a real closed
loop, so it gets the correct filter now. `Gam/Skeleton_3Axis.ino` needs the
same swap separately — not done by these files.

## Which edge, per axis

`cubli_gains.h` gives each axis two edge candidates, same edge direction
`e` but different `gB` (which pair of transverse corners is up):

| Axis | `e` | Candidate A | Candidate B |
|---|---|---|---|
| X (id 2) | `[1,0,0]` | `X[+1,+1]` (+Y,+Z up, 0.758°) | `X[-1,-1]` (-Y,-Z up, 0.837°) |
| Y (id 3) | `[0,1,0]` | `Y[+1,+1]` (+X,+Z up, 0.006°) | `Y[-1,-1]` (-X,-Z up, 0.007°) |
| Z (id 1) | `[0,0,1]` | `Z[+1,+1]` (+X,+Y up, 0.764°) | `Z[-1,-1]` (-X,-Y up, 0.844°) |

Stored as `kCandidates[3][2]`, indexed `[kAxis][gEdgeIdx]`. Every stage
resolves the second index **by measurement, not memory** — at startup, it
compares the measured `ghat` against both of the active axis's candidate
`gB` vectors and picks whichever one it actually agrees with, printing the
answer and a warning if the two are too close to call. Re-run with the `e`
serial command any time.

## Hardware status

All three wheels (X, Y, Z) have been run through the staged bring-up and
balance successfully on their respective edges. `kAxisWheelSign[3]` is
`+1.0f` across the board and confirmed for all three via each axis's own
Stage 1 pulse test — no sign flip was needed on this build. Re-verify per
axis rather than assuming it still holds if the mount or wiring changes
(Firmware Lessons S4).

## What's still open

- **IMU calibration** is still the 2D panel's numbers, copied forward with
  the same TODO as `Gam/Skeleton_3Axis.ino`. Telemetry-only risk in Stage 1
  (no feedback loop yet); a real accuracy problem from Stage 2 onward.
- **`Gam/Skeleton_3Axis.ino`'s own estimator** still needs the LERP→kP/kI
  filter swap these files already carry — separate, not done by this folder.

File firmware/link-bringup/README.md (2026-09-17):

# link-bringup — find out exactly where the WiFi link is broken

Six stages, each one hop longer than the last. Every stage isolates **one**
thing and gives a number that either passes or names the fault. Run them in
order. The first one that fails is your answer — and you never have to guess
between "the WiFi is broken" and "the wire is broken" again.

This exists because the failure you are chasing —  *no telemetry arrives* —
has at least nine distinct causes spread across three boards, two power
schemes and a firewall, and from the plot window they all look identical.

> **Nothing in Stages 0–5 can move a wheel.** No sketch in this folder opens
> CAN. Stage 6 flashes the real firmware and still keeps the motor bus dead.

## The ladder

| Stage | Powered by | Boards | Proves | Pass |
|---|---|---|---|---|
| [0 — Boards alive](Stage0_BoardsAlive/) | USB | either, alone | toolchain, COM ports, **USB CDC On Boot** | `[alive]` once a second on both |
| [1 — UART link](Stage1_UartLink/) | USB ×2 | both | jumpers crossed, common GND, 1 Mbaud clean, **each direction separately** | `acks=10 loss=0.0% garbage=0` on both monitors |
| [2 — WiFi join](Stage2_WiFiJoin/) | USB | XIAO | SSID, password, static IP on the right subnet | `[wifi] up` for 60 s with no drop |
| [3 — UDP echo](Stage3_UdpEcho/) | USB | XIAO | laptop↔XIAO **both directions**, under 250/s load | RTT < 50 ms, loss < 2 %, ≥ 240 round trips/s |
| [4 — Bridge throughput](Stage4_BridgeThroughput/) | USB ×2 | both | the **whole pipeline** at 250 lines/s, real grammar, no control law | `rate 249/s loss < 1%` |
| [5 — Rail power](Stage5_RailPower/) | **bench supply** | both | the LM2596 rail carries it, no USB anywhere | same numbers as Stage 4, held 2 min |
| [6 — Real firmware](Stage6_RealFirmware/) | bench supply | both | the actual build, **motor bus dead** | boot diagnostics + live telemetry + commands answered |

Stages 0–5 are all bench work with the cube power off or the motors dead.
Arming is deliberately outside this folder — see
[`../README.md`](../README.md) § *Bring-up sequence*.

## Start here if you are already stuck

You do not have to start at Stage 0 if you have a specific symptom:

| What you see | Go to |
|---|---|
| Nothing at all, no idea where to begin | [Stage 0](Stage0_BoardsAlive/) — 5 minutes, and it rules out two whole categories |
| XIAO's COM port shows no text | [Stage 0](Stage0_BoardsAlive/) — *USB CDC On Boot* |
| XIAO says `serial1_lines=0` | [Stage 1](Stage1_UartLink/) — it is the wire or GND |
| XIAO says `wifi=DOWN`, or never connects | [Stage 2](Stage2_WiFiJoin/) — the scan output names the reason |
| `wifi=up` but nothing reaches the laptop | [Stage 3](Stage3_UdpEcho/) — separates firewall from client isolation |
| Telemetry arrives but is choppy / slow / dies | [Stage 4](Stage4_BridgeThroughput/) — measures exact loss with no control law involved |
| It worked, then the XIAO **vanished** — no ping, no ARP entry | Power, not network. The board browned out or reset: see [the 5 V note](#the-5-v-pins-are-commoned--what-that-changes). Read its Serial Monitor to tell a reboot from a WiFi drop. |
| Works on USB power, not on the supply | [Stage 5](Stage5_RailPower/) — it is the rail, not the network |
| Link fine, firmware misbehaves | [Stage 6](Stage6_RealFirmware/) |

Already-flashed bridge and just want a verdict?
[`../link_check.py`](../cubli-ui/tools/link_check.py) walks the whole pipeline in one command.
This folder is what you use when `link_check.py` says "broken" and you need to
know **which part**.

## Power rules (read once, then never improvise)

**Never have cube power and USB connected at the same time.**

Both `Teensy VIN` and the XIAO's `5V` pin are tied to their board's USB 5 V
internally. With the rail live, plugging in USB puts the **laptop's 5 V
directly in parallel with the LM2596's 5 V** — two stiff sources, neither
current-limited toward the other, whichever is higher back-feeding the other.
That can damage the laptop's USB port, the LM2596, or a board.

On this build the supply feeds **both** boards and you cannot power one
without the other. **This ladder is arranged so that never matters:**

| | Rail | XIAO USB | Teensy USB |
|---|---|---|---|
| Stages 0–4 | **off** | yes | yes |
| Stage 5–6 | **on** | **no** | **no** |

Stages 0–4 run on USB power with the rail dead. Stage 5–6 run on the rail with
no cable anywhere. You never need both at once.

### The 5 V pins are commoned — what that changes

On this build the XIAO's `5V` pin and the Teensy's `VIN` are the **same node**,
both fed from the LM2596. With the rail off and one USB cable plugged in, that
cable powers **both boards** — plus anything else on the 5 V rail.

That is electrically fine (one source, and back-feeding the LM2596's *output*
has no path to its input through a non-synchronous buck), but two things
follow:

- **"One board at a time" is not achievable.** Plugging in the XIAO boots the
  Teensy too. Stage 0 and Stage 1 are written accordingly.
- **All of it flows through one USB connector.** The Teensy's ~100 mA idle
  travels through the XIAO's USB port, its 5 V trace and its `5V` pin. Against
  a 500 mA USB 2.0 port:

  | | |
  |---|---|
  | XIAO continuous (with `setSleep(false)`) | ~100 mA |
  | XIAO WiFi TX peaks | up to 300 mA |
  | Teensy 4.1 idle | ~100 mA |
  | **peak through one port** | **~400 mA+** |

  Use a **USB 3.0 port (900 mA) or a powered hub** for the XIAO. A port that
  current-limits browns out the XIAO, which drops off WiFi and vanishes from
  the ARP table — a failure that looks like a network fault and is not one.
  Symptom seen on this hardware: Stage 3 passing twice, then the board
  disappearing entirely between runs.

Plugging **both** USB cables ties two ports' VBUS together. On the same
laptop that is tolerated — one internal 5 V rail, common ground. **Never
across two different hosts.**

The permanent fix is the same jumper from
[Stage 5](Stage5_RailPower/#if-you-want-usb-and-rail-power-anyway): put a
2-pin header in the XIAO's 5 V feed. Then USB powers only the XIAO, the rail
powers only what you want, and the whole class of problem goes away.

**Order, every time:** power up → cube power **OFF**, plug USB, flash, **unplug
USB**, cube power **ON**. Power down → cube power **OFF** first, then USB.
Wiring → all power off before touching D6/D7/GND; GND connects first and
disconnects last.

If you do want both simultaneously — mainly so you can run
`link_check.py --serial`, the only conclusive directional test — the options
and their trade-offs are in [Stage 5](Stage5_RailPower/#if-you-want-usb-and-rail-power-anyway).
The short version: **put a jumper in the XIAO's 5 V feed.** Ten minutes, and
the constraint goes away permanently.

## The CDC stall (the one that wastes the most time)

Leaving the XIAO's USB cable attached with **no application reading the port**
collapses the bridge. Measured on this hardware, not theorised:

```
loop() rate, cable attached, monitor closed:   0.49 iterations/s
```

`pollUdpIn()` and `pollSerial1Out()` each handle exactly **one item per
`loop()` iteration**, so the bridge then relays **0.5 lines/s** — against the
250/s the corner build emits. Telemetry appears completely dead, for a reason
that looks nothing like the actual cause.

Why: on this chip `if (Serial)` is true whenever the cable is plugged in, even
with nothing draining the buffer, and `printf()` then blocks ~2 s. The 1 s gate
on the status print has always expired by the time it returns, so it re-blocks
every iteration.

**Three ways to be safe, in order:**

1. **Unplug the XIAO's USB and power it from the 5 V rail** — the normal
   operating configuration anyway.
2. Keep a serial monitor **open and reading** — that drains the buffer. This
   is what Stages 0–4 assume, and why they tell you to keep the monitors open.
3. Set `ENABLE_LINK_STATUS 0` in the bridge sketch if the cable must stay
   attached unattended.

Every XIAO sketch in this folder carries the same `availableForWrite()` guard
the bridge does, so it skips its print instead of stalling. Belt and braces —
rule 1 is still the one to follow.

**Signature:** Stage 3 echoes trickling back ~2 s apart, or Stage 4 reporting a
rate near 0.5/s.

## WiFi modem sleep (found at Stage 3, 2026-08-17)

The esp32 core defaults a station to `WIFI_PS_MIN_MODEM`: the radio parks
between the AP's beacons and only wakes to collect buffered downlink traffic.
Measured here at **−32 dBm**, which is as strong as a link gets:

```
rtt  min=3.9   med=75.5   p95=93.5   max=93.5 ms
```

The 3.9 ms is what the RF path actually costs. The rest is sleep, and the
~100 ms ceiling is the iPhone hotspot's beacon interval. The tell is the
**shape**: a fast best case with a median an order of magnitude worse and a
hard ceiling. Weak signal and congestion both look nothing like this.

It matters more than the latency number suggests:

- every command, including `a0`, is delayed by up to a beacon interval;
- the PC keepalive arrives in bursts, so the Teensy's **300 ms link watchdog
  can time out and auto-disarm mid-balance** for no real reason — a phantom
  fault indistinguishable from a genuine link failure;
- packets buffered for a sleeping station are dropped once the AP's queue for
  it fills, which is routine at 250 lines/s.

**Fix:** `WiFi.setSleep(false)` — now in
[`../xiao_teensy_bridge/`](../cubli-ui/xiao/xiao_teensy_bridge/xiao_teensy_bridge.ino),
[`firmware/XIAO/xiao_teensy_bridge/`](../cubli-ui/xiao/xiao_teensy_bridge/xiao_teensy_bridge.ino)
and both XIAO sketches in this ladder. Costs ~100 mA continuous, already
inside the ESP32-C6 budget in
[`Electrical-Design-Guide.md`](../../docs/electronics/Electrical-Design-Guide.md)
§2.2. **Reflash the XIAO to pick it up.**

`stage3_udp_echo.py` now names this pattern when it sees it, and separates
**late** replies from **lost** ones — with modem sleep on, replies routinely
arrive after the next ping goes out, which an earlier version of the script
scored as 13 % loss when almost none of it was loss.

## Keep these five values identical everywhere

Every XIAO sketch in this ladder and
[`../xiao_teensy_bridge/xiao_teensy_bridge.ino`](../cubli-ui/xiao/xiao_teensy_bridge/xiao_teensy_bridge.ino)
must agree on:

```cpp
WIFI_SSID    WIFI_PASSWORD    XIAO_IP    XIAO_GATEWAY    XIAO_SUBNET
```

and the Python scripts' `XIAO_IP` must match too (or pass `--ip`). A test
sketch that passes with different settings than the bridge that "doesn't work"
is a trap this project has already fallen into.

Two more that must match across boards: **1000000 baud** (`kLinkBaud` on the
Teensy, `TEENSY_LINK_BAUD` on the XIAO) and **UDP port 4210**.

### Network choice

Use a **phone hotspot or a network you control**. Guest/campus networks
(`ES-Guest` here) run **client isolation**: the laptop and the XIAO both reach
the internet and never each other. Stage 2 passes perfectly, Stage 3 can never
pass, and no firmware change fixes it.

Keep the SSID **plain ASCII**. The default iPhone name contains U+2019, a
curly apostrophe — typing a normal `'` never matches and the join fails
silently. This repo uses `cubli1`.

## Wiring, once, for all stages

```
Teensy Serial1 TX1 (pin 1)  ---->  XIAO D7 (RX)
Teensy Serial1 RX1 (pin 0)  <----  XIAO D6 (TX)
Teensy GND                  -----  XIAO GND      <- not optional
```

Crossed, and 3.3 V logic on both sides — no level shifter, and never 5 V on
D6/D7.

## What is in here

```
Stage0_BoardsAlive/     xiao_hello/          teensy_hello/
Stage1_UartLink/        xiao_uart_echo/      teensy_uart_ping/
Stage2_WiFiJoin/        xiao_wifi_join/
Stage3_UdpEcho/         xiao_udp_echo/       stage3_udp_echo.py
Stage4_BridgeThroughput/ teensy_csv_faker/   stage4_rate_check.py
Stage5_RailPower/       (README only — reuses Stage 4)
Stage6_RealFirmware/    (README only — flashes ../CornerBalance_WiFi/)
```

Python needs only the standard library. `matplotlib` is required by the real
telemetry scripts one level up, not by anything here.

Nothing in this folder modifies the flight builds. The bridge sketch used from
Stage 4 on is the existing
[`../xiao_teensy_bridge/`](../cubli-ui/xiao/xiao_teensy_bridge/xiao_teensy_bridge.ino),
unchanged.

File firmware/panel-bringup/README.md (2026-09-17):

# Panel Bring-Up — Teensy 4.1 / moteus-n1 / BMI270

Staged Arduino IDE firmware for bringing the Stage 1 planar panel rig up
from "nothing tested" to closed-loop balancing, one confidence-building
step at a time. Companion to [`../../docs/simulation/`](../../docs/simulation/)
(plant, LQR derivation, validation gates) — this is the hardware side of
that pipeline.

## Files

| File | Motor can move? | What it tests |
|---|---|---|
| `test_control.txt` | No — hard-wired off | Stage 0: estimator only (IMU sign, mount offset, complementary filter) |
| `Stage1_OpenLoopTorque/` | Yes — fixed pulse only | First real torque command; the two sign checks that matter most before anything closes the loop |
| `Stage2_DampingOnly/` | Yes — closed loop | Rate feedback only (`k2`), full safety scaffold introduced |
| `Stage3_PositionDamping/` | Yes — closed loop | Adds position feedback (`k1`), gain ramped 0.1→1.0 by hand |
| `Stage4_FullLaw/` | Yes — closed loop | Adds momentum management (`k3`) — wheel should unwind after corrections |
| `Stage5_Release/` | Yes — closed loop, unsupported | Panel released with rails + e-stop; the actual balancing attempt |

`test_control.txt` stays a loose file (not `.ino`) by design — everything
else is a self-contained Arduino IDE sketch in a folder named after itself,
so each opens directly.

## Docs

- **`Arduino-Bring-Up-Plan-Sections-2b-2d.md`** — the original
  procedure/checklists these sketches implement, stage by stage.
- **`Bring-Up-Stages-Implementation-Notes.md`** — what each file's code
  actually does and why, including two real bugs found and fixed during
  hardware bring-up on this rig:
  - `SetPosition()`'s default wire format silently drops every `Command`
    field except `position`/`velocity` — torque commands were never
    reaching the moteus until a custom `Format` was passed explicitly.
  - The wheel's physical mounting convention was backwards relative to the
    LQR model's sign convention (confirmed via Stage 1 sign check 4) —
    fixed with a single `kWheelSign` constant at the hardware boundary,
    not by touching the derived gains.

Both are worth reading before assuming any of this "just works" on a
different rig — they compiled cleanly and looked correct; only real
hardware testing caught either one.

## Gains currently deployed

```
K = [-1.0998, -0.1232, -0.001732]   (N*m/rad, N*m/(rad/s), N*m/(rad/s))
```

From `cubli_panel_simscape_gates.m` Gate 7, LQR on the measured-mode plant
(`../../matlab/cubli_panel_params.m`). Closed-loop poles for this `K`:
≈ **-12.5, -9.7, -6.3 rad/s** (all real) — see the Implementation Notes for
where two different `-15/-9/-6`-style figures floating around elsewhere
came from and why they were wrong.

Retuning these follows [Panel Controller Workflow](../../docs/simulation/Panel-Controller-Workflow.md)
step 4: measure `Theta` from a free-swing test on the built panel, update
the plant, re-run `lqr()`, re-flash. See the Implementation Notes' closing
section on fine-tuning for the fuller version of that process.

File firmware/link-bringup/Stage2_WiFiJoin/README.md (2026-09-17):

# Stage 2 — The XIAO joins the network

**Power:** cube power **OFF**, XIAO USB only. The Teensy is irrelevant here.
**Can anything move?** No.

## Proves

The board associates with your AP and holds the **static address** you gave
it. Nothing more — reachability is Stage 3's job, and the two failures look
identical from the laptop.

## Run

1. In `xiao_wifi_join/xiao_wifi_join.ino` set `WIFI_SSID`, `WIFI_PASSWORD`,
   `XIAO_IP` / `XIAO_GATEWAY` / `XIAO_SUBNET`.
2. Upload. Serial Monitor at 115200.

> **Keep those five values byte-identical** here, in Stage 3's sketch, and in
> [`xiao_teensy_bridge.ino`](../../cubli-ui/xiao/xiao_teensy_bridge/xiao_teensy_bridge.ino).
> A test sketch that passes with different settings than the bridge that
> "doesn't work" is a trap this project has already fallen into once.

## Pass

```
 connected!
  IP:      172.20.10.14
  gateway: 172.20.10.1
  RSSI:    -52 dBm
[wifi] up ip=172.20.10.14 rssi=-52dBm uptime=12s
```

The `[wifi] up` line must keep printing for **60 s without a single `link
DROPPED`**. A join that flaps every few seconds shows up three stages later as
"random telemetry dropouts" and is very hard to recognise there.

Then, from the laptop: `ping 172.20.10.14`. A reply is good news but **not**
proof — some APs pass ICMP and still block client-to-client UDP. Stage 3
decides.

## If it fails

The sketch scans on failure and lists every SSID it can hear, with RSSI and a
flag on any name containing **non-ASCII characters**.

| Reported status | Meaning |
|---|---|
| `NO_SSID_AVAIL` + your SSID absent from the scan | Name mismatch, out of range, or the AP is **5 GHz-only** (this radio is 2.4 GHz here and will never see it) |
| `NO_SSID_AVAIL` + your SSID **present** in the scan | The name you typed is not the name that is broadcast — compare character by character |
| `CONNECT_FAILED` | Wrong password, WPA2-Enterprise (unsupported), or a captive portal |
| Connected, but IP ≠ `XIAO_IP` | `WiFi.config()` was overridden. Use the address it actually printed |
| `!! XIAO_IP and XIAO_GATEWAY are NOT in the same subnet` | Fix the addresses. This produces a board that reports healthy and is unreachable — the most confusing failure in the ladder |

### The curly-apostrophe trap

The default iPhone hotspot name contains **U+2019**, a curly apostrophe that
is three UTF-8 bytes. Typing a normal `'` in `WIFI_SSID` never matches and the
join fails with no useful error. Rename the phone to plain ASCII — this repo
uses `cubli1`. The scan output flags any SSID with non-ASCII bytes for exactly
this reason.

### Do not use a guest / campus network

`ES-Guest` was abandoned for this project: it runs **client isolation**, so
the laptop and the XIAO both reach the internet and never each other. Stage 2
passes perfectly and Stage 3 can never pass. No firmware change fixes it.

→ Then [Stage 3](../Stage3_UdpEcho/).

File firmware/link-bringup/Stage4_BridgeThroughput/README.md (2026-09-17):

# Stage 4 — The whole pipeline at the real data rate, no control law

**Power:** cube power **OFF**. Both boards on their **own USB cable**, into the
same laptop. Jumpers connected. Nothing touches the LM2596 rail.
**Can anything move?** **No** — the faker never opens CAN. There is no CAN
traffic on the bus at all.

## Proves

`Teensy → Serial1 @ 1 Mbaud → XIAO → WiFi/UDP → laptop`, exercised exactly the
way `CornerBalance_WiFi.ino` will exercise it: **21 CSV fields, 250 lines/s**,
the same command grammar, the same `#` console lines — with the moteus, the
BMI270, the estimator, the control law and arming all absent.

That is the point. When this passes, the transport is a known-good constant.
The first time you run the real firmware, anything wrong is in the firmware.
Skip this stage and you debug both at once, on a cube that can throw itself
off the bench.

**The XIAO runs the real bridge from here on** —
[`../../xiao_teensy_bridge/xiao_teensy_bridge.ino`](../../cubli-ui/xiao/xiao_teensy_bridge/xiao_teensy_bridge.ino).
Flash it now. Stage 4 is the last chance to test that sketch against a data
source that cannot hurt anyone.

## Run

1. XIAO ← `../../xiao_teensy_bridge/xiao_teensy_bridge.ino` (same five config
   values you used in Stages 2–3).
2. Teensy ← `teensy_csv_faker/teensy_csv_faker.ino`.
3. `python stage4_rate_check.py`

```bash
python stage4_rate_check.py                  # 20 s
python stage4_rate_check.py --seconds 120    # soak it
python stage4_rate_check.py --command a1     # also test laptop -> Teensy
```

Then, once it passes, point the **real plotter** at the faker:

```bash
python ../../telemetry_python_wifi_corner.py
```

The panels fill with slow sinusoids. That proves matplotlib, the CSV parsing,
the 21-column layout, the command console and the CSV-on-close — before any of
it is load-bearing. Type `a1` and watch the `armed` column flip.

## Pass

```
rate 249.6/s   loss 0.2%   longest gap 2 lines   out-of-order 0
```

Under ~1 % loss, in ones and twos, is normal UDP-over-WiFi and plots perfectly
smoothly.

### Exact loss, not an average

The faker sets `t_ms = seq*4`, so `seq = t_ms/4` is recoverable from every
line. "Telemetry looks choppy" becomes a number — and, more usefully, a
*shape*: singles mean radio noise, long runs mean the bridge stalled or the
WiFi roamed. A packets-per-second average hides both.

## If it fails

| Symptom | Cause |
|---|---|
| rate collapses to **~0.5/s** | The XIAO's USB is plugged in with nothing reading it. Its CDC blocks ~2 s per print; the bridge relays one line every two seconds. See [the CDC stall](../README.md#the-cdc-stall-the-one-that-wastes-the-most-time). |
| loss in **long runs** | WiFi roaming or the bridge falling behind. Check RSSI on the `[status]` line. |
| rate ≈ 125/s, loss ≈ 50 % | `loop()` running at half the needed rate — one line is relayed per iteration. |
| 0 lines but `#` answers arrive | Commands work, telemetry does not: the Teensy is in `t0` (USB) mode. Send `t1`. |
| 0 lines, and the Teensy says `lines_out=0 tx_skipped=250` | The Teensy never got a byte onto the wire. Serial1's TX buffer is smaller than one line, so the room check in `emitLine()` rejects all of them — Teensy 4.x defaults to **40 B** against a ~200 B line. Fixed by `Serial1.addMemoryForWrite()` in `setup()`; if you see this, you are running an older faker. |
| 0 lines, nothing at all | Back to Stage 3. If Stage 3 passes, the fault is Serial1 → back to Stage 1. |
| `--command a1` gets no `#` reply | The laptop → Teensy direction is broken: XIAO D6 → Teensy pin 0. Stage 1 tests exactly this. |

### Which side is dropping — the one cross-check worth doing

Compare the Teensy's own USB `[faker]` line against the script:

| | Meaning |
|---|---|
| `lines_out` = lines received | perfect |
| received is lower | lost **after** the Teensy — the XIAO relay or the air link |
| `tx_skipped` nonzero | lost **before** the XIAO — the Serial1 TX buffer was full, the Teensy could not even hand the line over |

From the laptop alone those are indistinguishable, which is why the faker
counts them.

→ Then [Stage 5](../Stage5_RailPower/) — the same test, on the bench supply.

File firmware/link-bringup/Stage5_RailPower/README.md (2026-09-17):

# Stage 5 — The same test, powered from the bench supply

**Power:** cube power **ON** (logic rail only — motor bus **dead**). **No USB
cable on either board.**
**Can anything move?** No. The faker still never opens CAN, and the motor bus
is off anyway.
**New code:** none. Same faker, same bridge, same script as Stage 4.

## Why this is a separate stage

Stage 4 passing on USB power does **not** prove the link works on the rail.
Everything electrical changes:

| | USB power (Stage 4) | Rail power (Stage 5) |
|---|---|---|
| 5 V source | laptop, stiff, well filtered | LM2596 at 22 → 5 V, switching |
| ground | shared through the laptop | star ground near the LM2596 |
| XIAO current | irrelevant | ~100 mA typical, **300 mA peaks on WiFi TX** |
| diagnostics | both USB monitors | UDP only — no `[status]`, no `[faker]` |

The WiFi TX peak is the one that bites. If the rail sags on every transmit
burst, the XIAO brown-out resets, rejoins over ~2–3 s, and you see telemetry
that "works but keeps cutting out" — with no serial port attached to tell you
why. That is worth ten minutes of deliberate testing now rather than during a
balance run.

## ⚠️ Power rules — the constraint you actually have

You said it plainly: with the supply connected, **the Teensy and the XIAO both
get 5 V and you cannot separate them.** That is exactly why this ladder is
built the way it is.

**Never have cube power and USB connected at the same time.** Both `Teensy
VIN` and the XIAO's `5V` pin are tied to their board's USB 5 V internally, so
plugging in USB while the rail is live puts the **laptop's 5 V directly in
parallel with the LM2596's 5 V** — two stiff sources, neither current-limited
toward the other. Whichever sits higher back-feeds the other. That can damage
the laptop's USB port, the LM2596, or a board.
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

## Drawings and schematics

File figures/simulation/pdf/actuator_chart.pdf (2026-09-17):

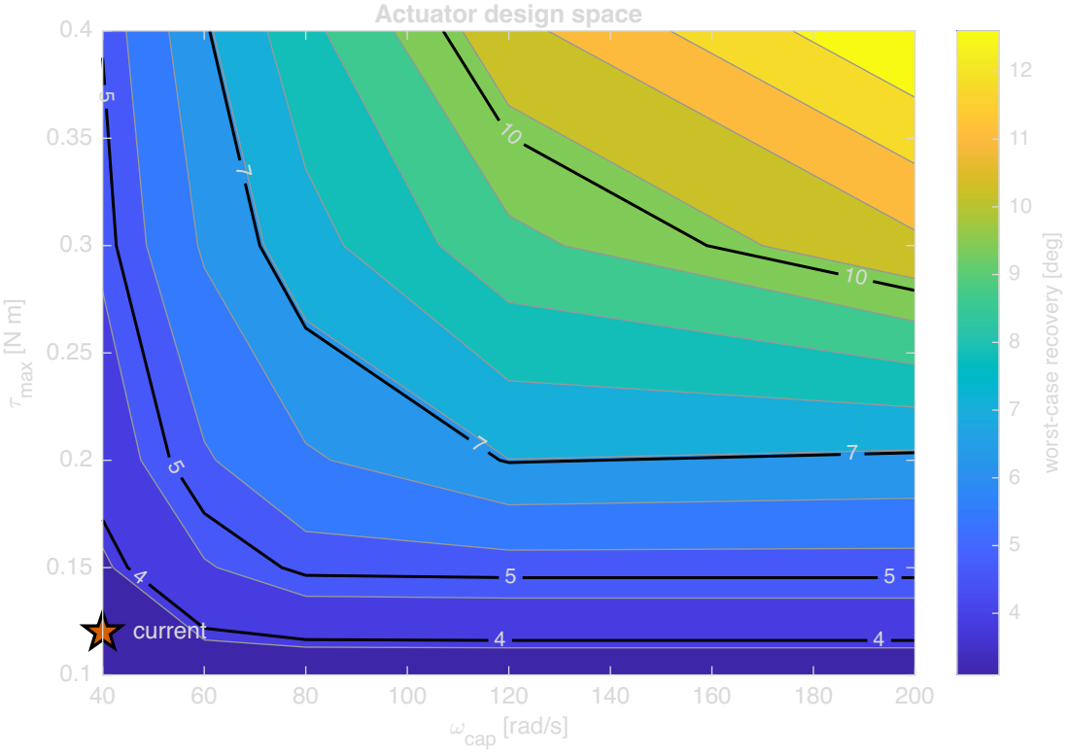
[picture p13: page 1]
sig; max [N m]

worst-case recovery [deg]

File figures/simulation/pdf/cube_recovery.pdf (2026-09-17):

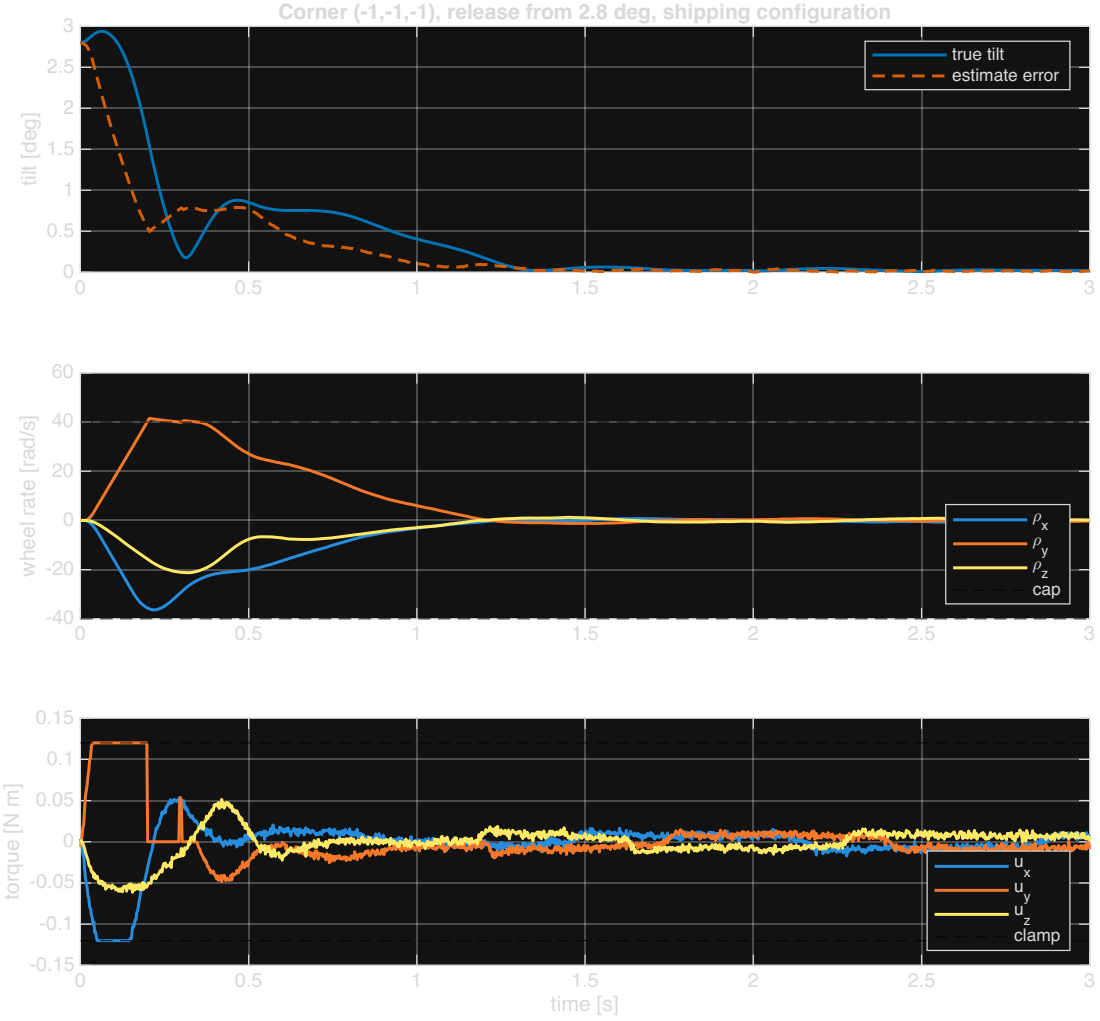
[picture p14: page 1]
tilt [deg]; Corner (-1,-1,-1), release from 2.8 deg, shipping configuration; time [s]; torque [N

true tilt
estimate error

wheel rate [rad/s]

x ; y ;

z cap

u x
u y u z

clamp

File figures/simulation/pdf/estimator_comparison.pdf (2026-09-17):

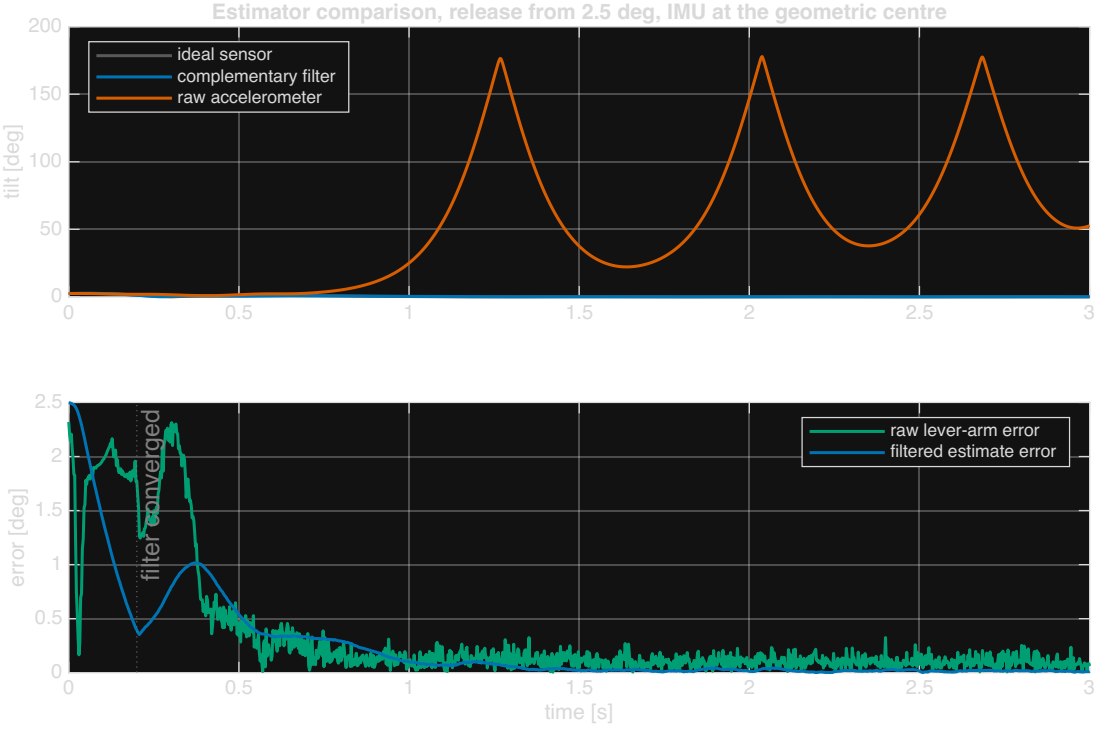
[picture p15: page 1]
tilt [deg]; Estimator comparison, release from 2.5 deg, IMU at the geometric centre; time [s]; error [deg]; filter conv; erg

ideal sensor complementary filter

raw accelerometer

raw lever-arm error
filtered estimate error

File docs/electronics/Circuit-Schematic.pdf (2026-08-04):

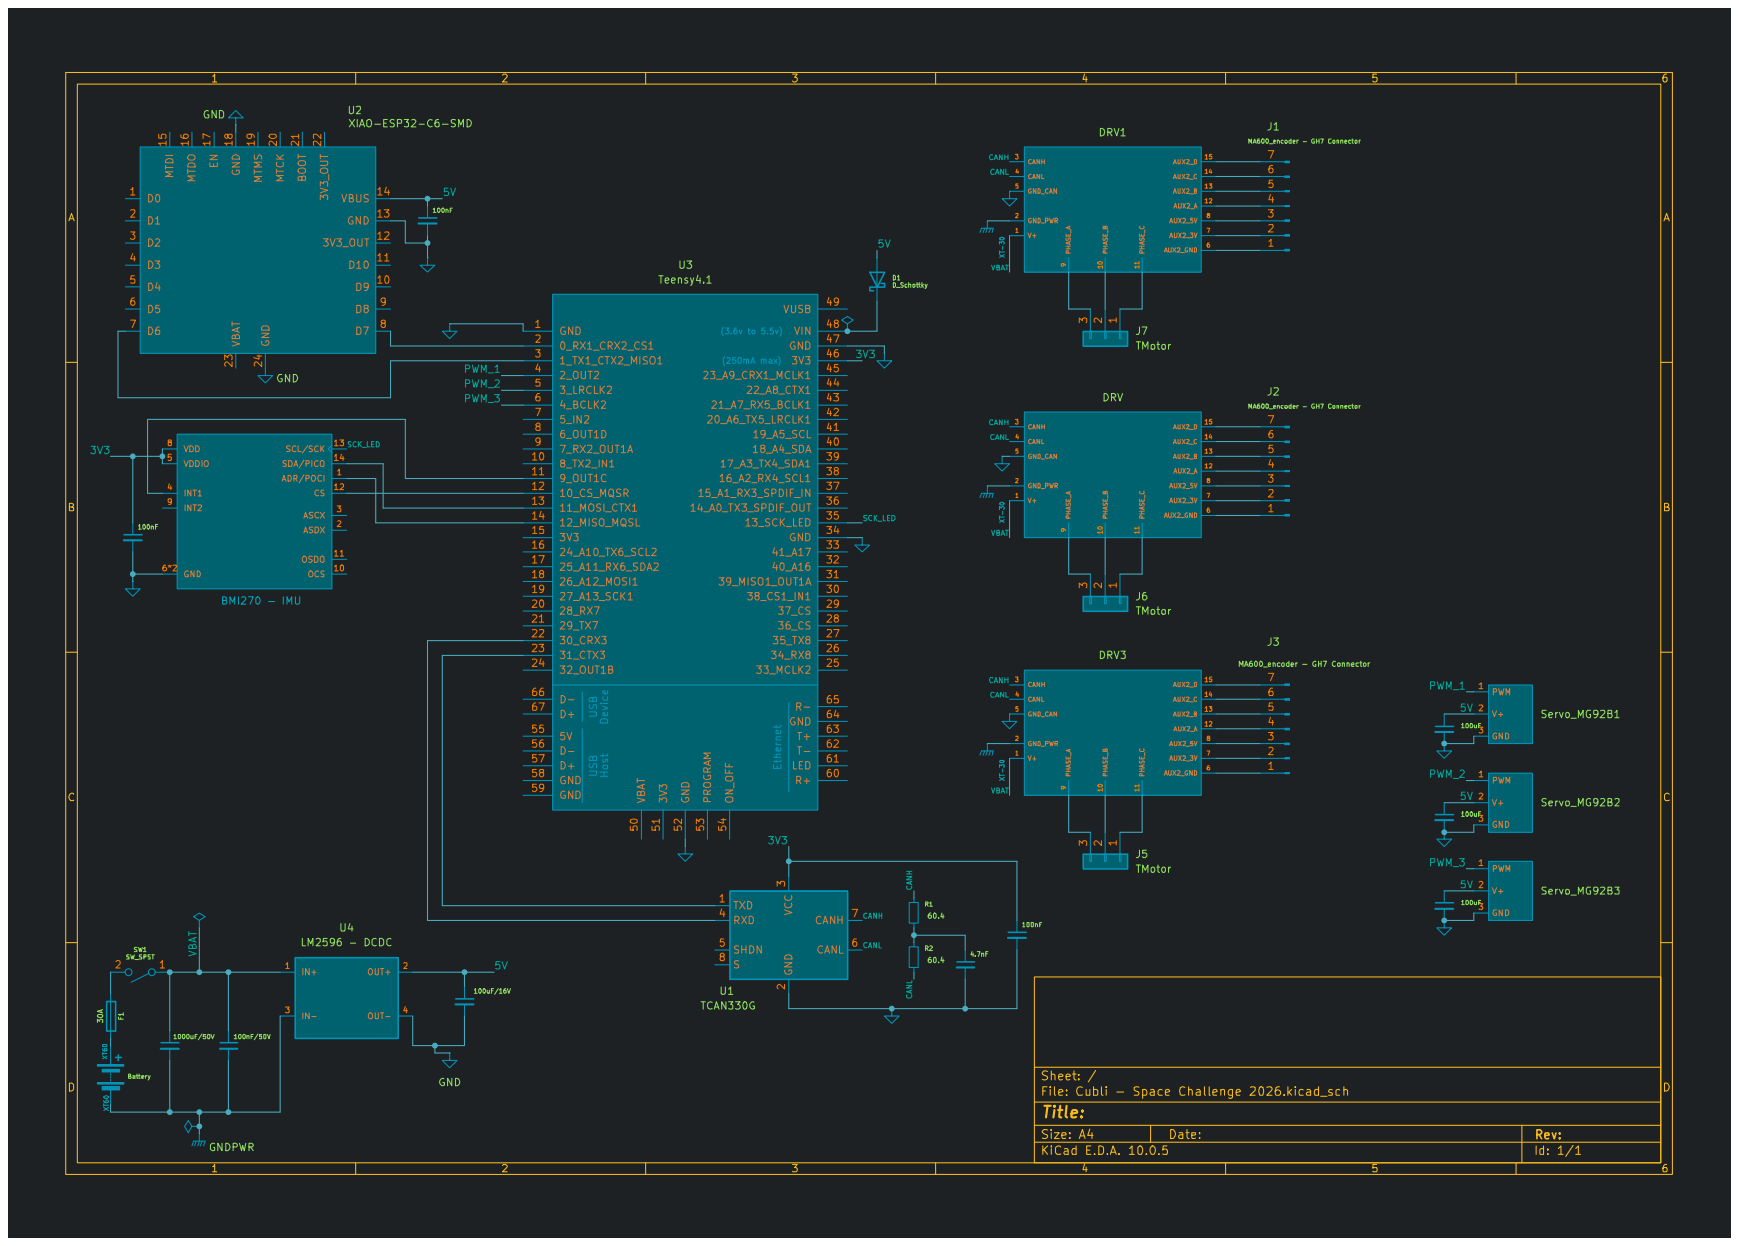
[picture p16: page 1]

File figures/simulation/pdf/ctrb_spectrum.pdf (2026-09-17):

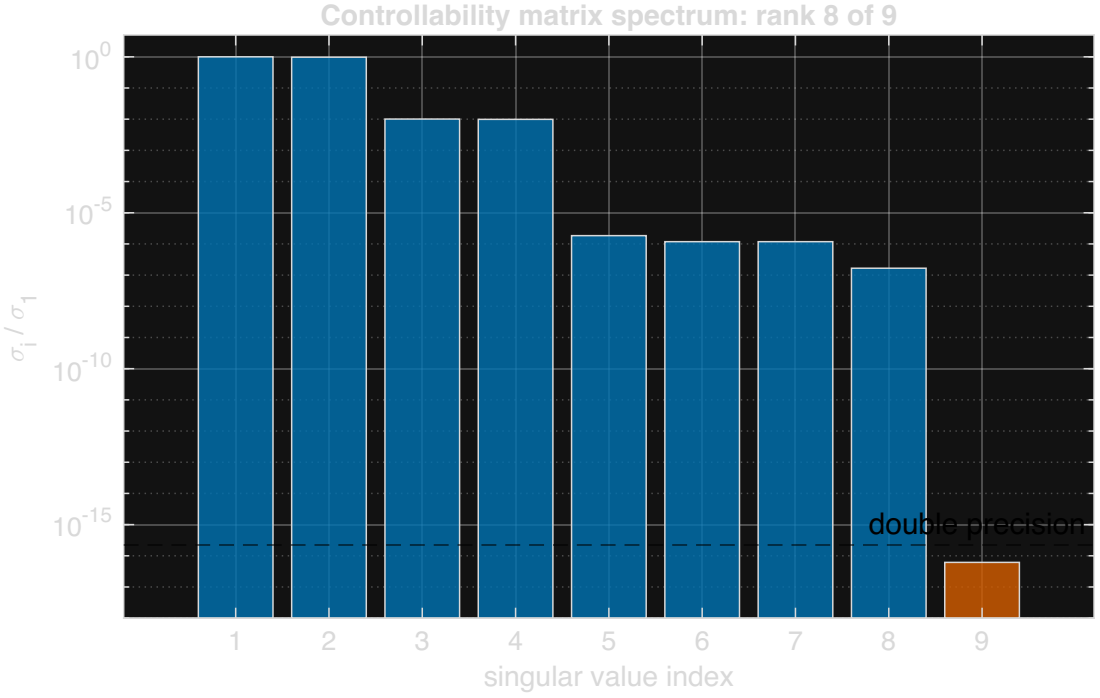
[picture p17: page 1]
double precision

Controllability matrix spectrum: rank 8 of 9

singular value index

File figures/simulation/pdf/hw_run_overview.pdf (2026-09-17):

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

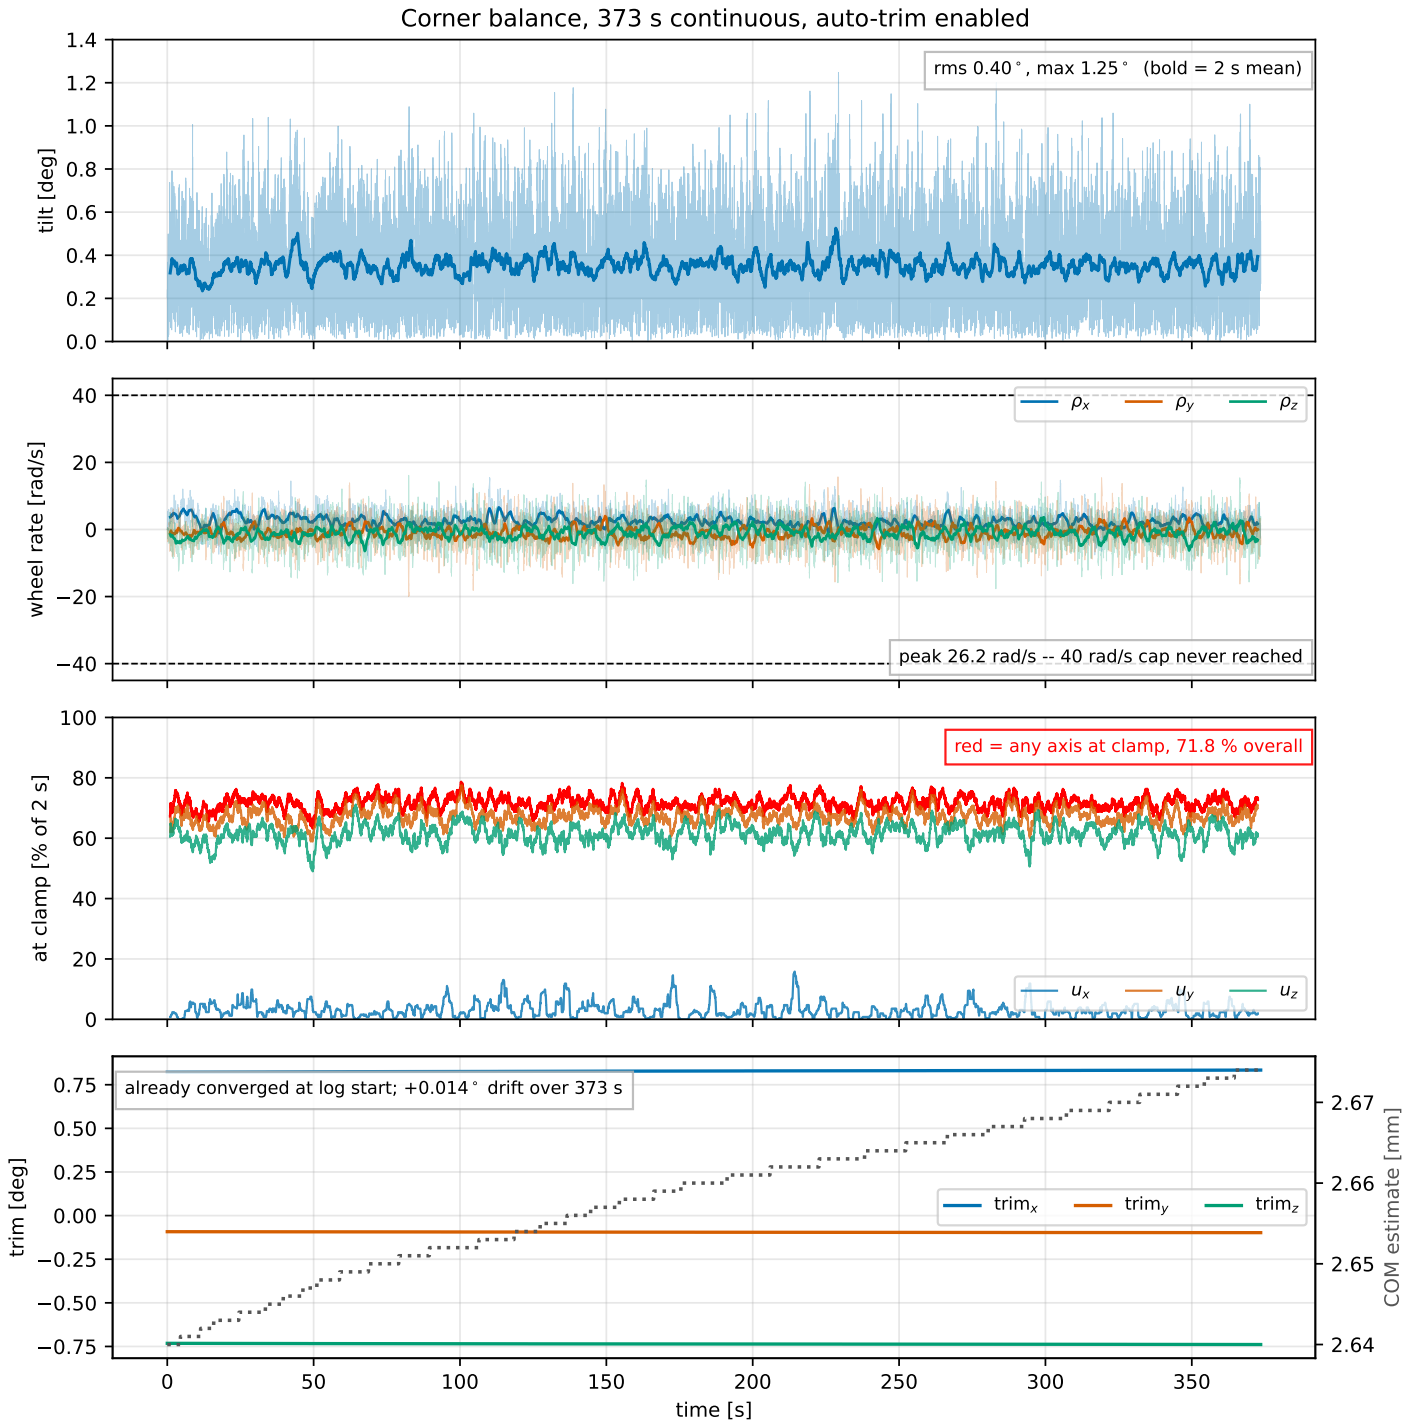
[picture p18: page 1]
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

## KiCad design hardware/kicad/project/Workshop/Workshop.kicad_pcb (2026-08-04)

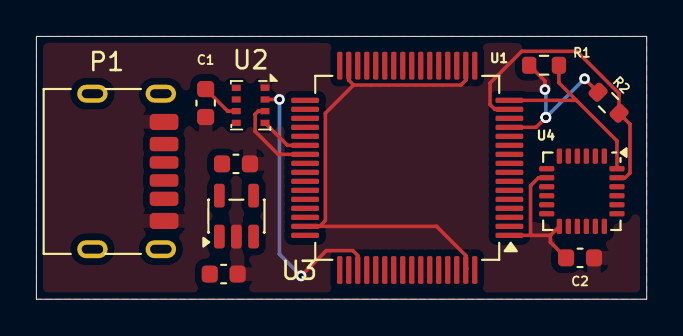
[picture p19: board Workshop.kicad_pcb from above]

Board: 2 copper layers, 33.9 x 14.6 mm, 11 parts (0 on the bottom side), 10 nets.

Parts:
C1, C2: 100nF; C_0603_1608Metric
Cin1: 1uF; C_0603_1608Metric
Cout1: 1uF; C_0603_1608Metric
P1: USB_C_Plug_USB2.0; USB_C_Receptacle_HRO_TYPE-C-31-M-17
R1, R2: 4.7k; R_0603_1608Metric
U1: STM32F446RETx; LQFP-64_10x10mm_P0.5mm
U2: BMP280; Bosch_LGA-8_2x2.5mm_P0.65mm_ClockwisePinNumbering
U3: MCP1804x-3302xOT; SOT-23-5
U4: MPU-6050; InvenSense_QFN-24_4x4mm_P0.5mm

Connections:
+3.3V: C1.1, C2.1, Cout1.1, R1.1, R2.1, U1.1 (VBAT), U1.13 (VDDA), U2.6 (VDDIO), U2.8 (VDD), U3.5 (VOUT), U4.8 (VLOGIC), U4.13 (VDD)
+5V: Cin1.1, P1.A9 (VBUS), P1.B9 (VBUS), U3.1 (VIN), U3.4 (~SHDN)
/CSB: U1.51 (PC10), U2.2 (CSB)
/IMU_SCL: R2.2, U1.15 (PA1), U4.23 (SCL)
/IMU_SDA: R1.2, U1.16 (PA2), U4.24 (SDA)
/SCK: U1.38 (PC7), U2.4 (SCK)
/SDI: U1.39 (PC8), U2.3 (SDI)
/SDO: U1.40 (PC9), U2.5 (SDO)
GND: C1.2, C2.2, Cin1.2, Cout1.2, P1.A12 (GND), P1.B12 (GND), U2.1 (GND), U2.7 (GND), U3.2 (GND), U4.18 (GND)
unnamed: U1.18 (VSS), U1.31 (VSS), U1.47 (VSS), U1.63 (VSS)

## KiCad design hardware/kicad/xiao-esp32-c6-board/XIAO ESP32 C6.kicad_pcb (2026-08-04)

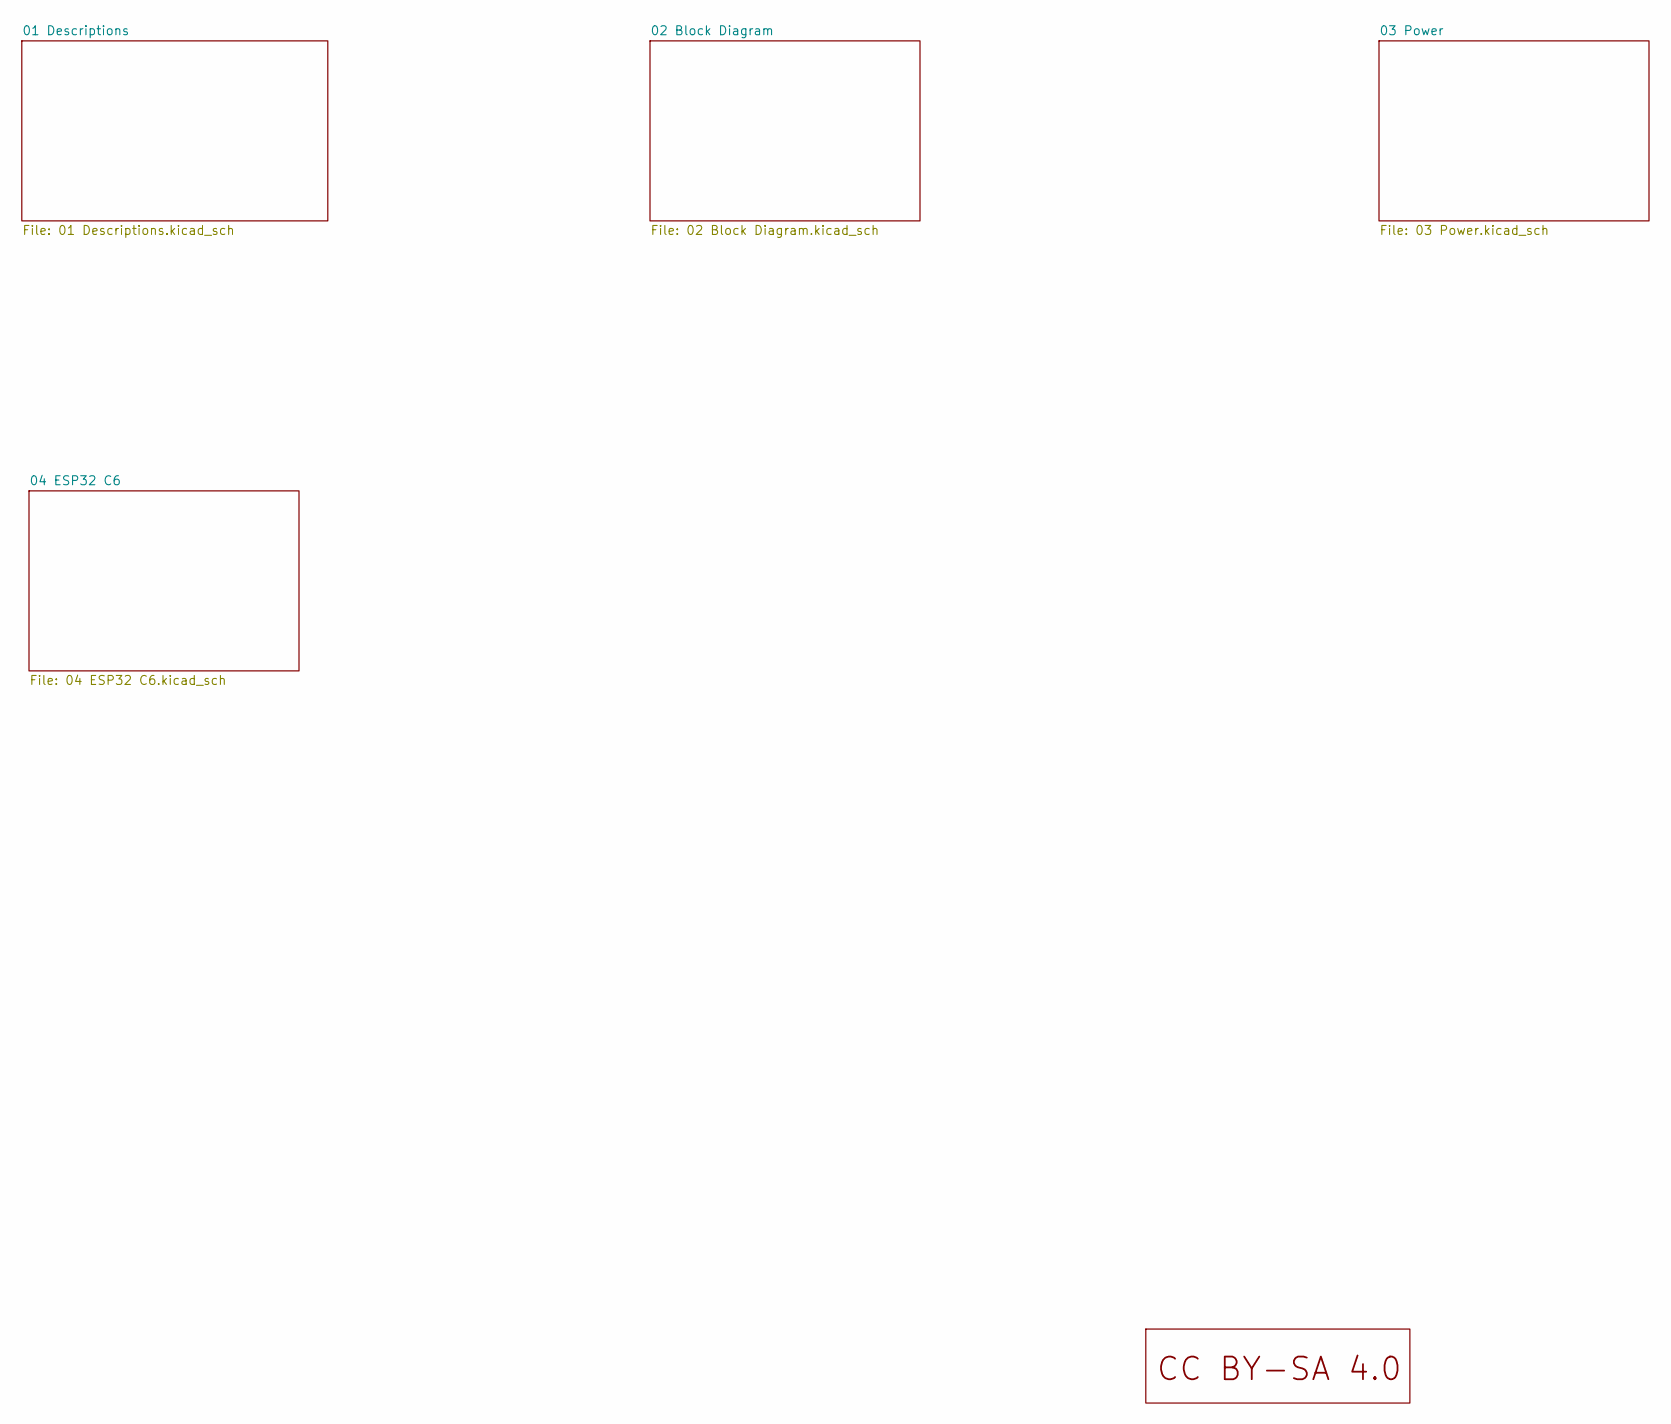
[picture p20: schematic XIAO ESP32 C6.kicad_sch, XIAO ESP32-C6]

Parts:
U6: LOGO_CC_BY-SA_4.0

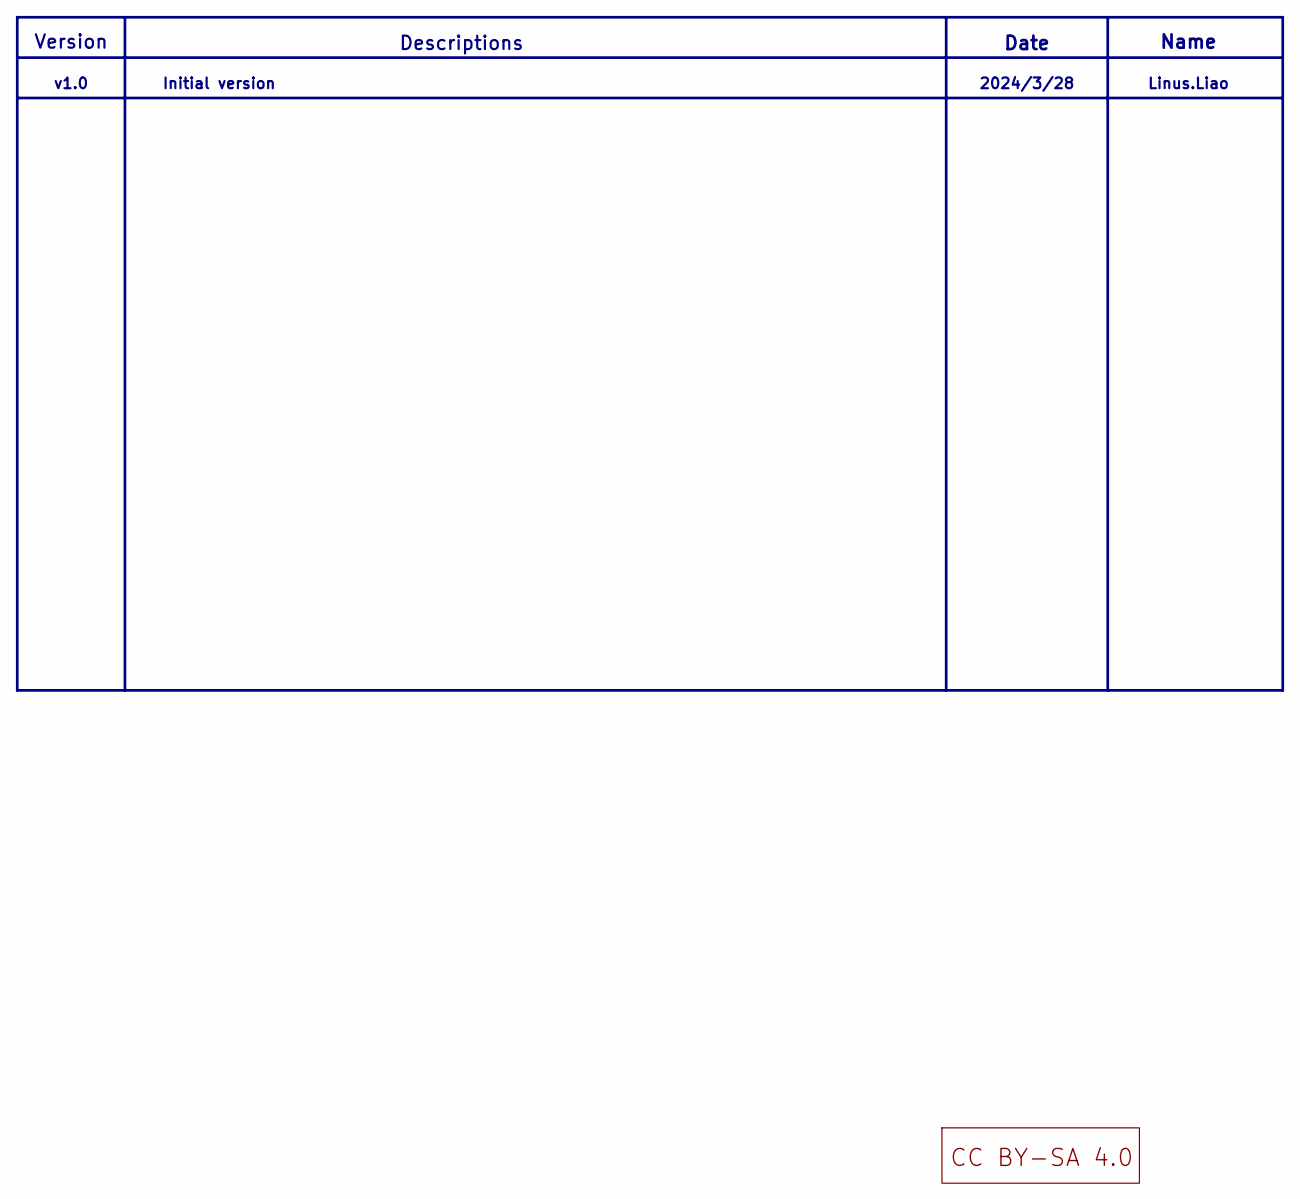
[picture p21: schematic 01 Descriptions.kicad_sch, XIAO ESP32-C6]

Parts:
U7: LOGO_CC_BY-SA_4.0

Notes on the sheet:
Date
Descriptions
Linus.Liao
2024/3/28
v1.0
Initial version
Name
Version

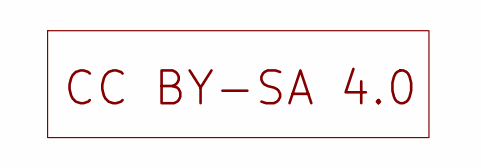
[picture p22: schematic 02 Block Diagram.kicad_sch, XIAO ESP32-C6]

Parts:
U8: LOGO_CC_BY-SA_4.0

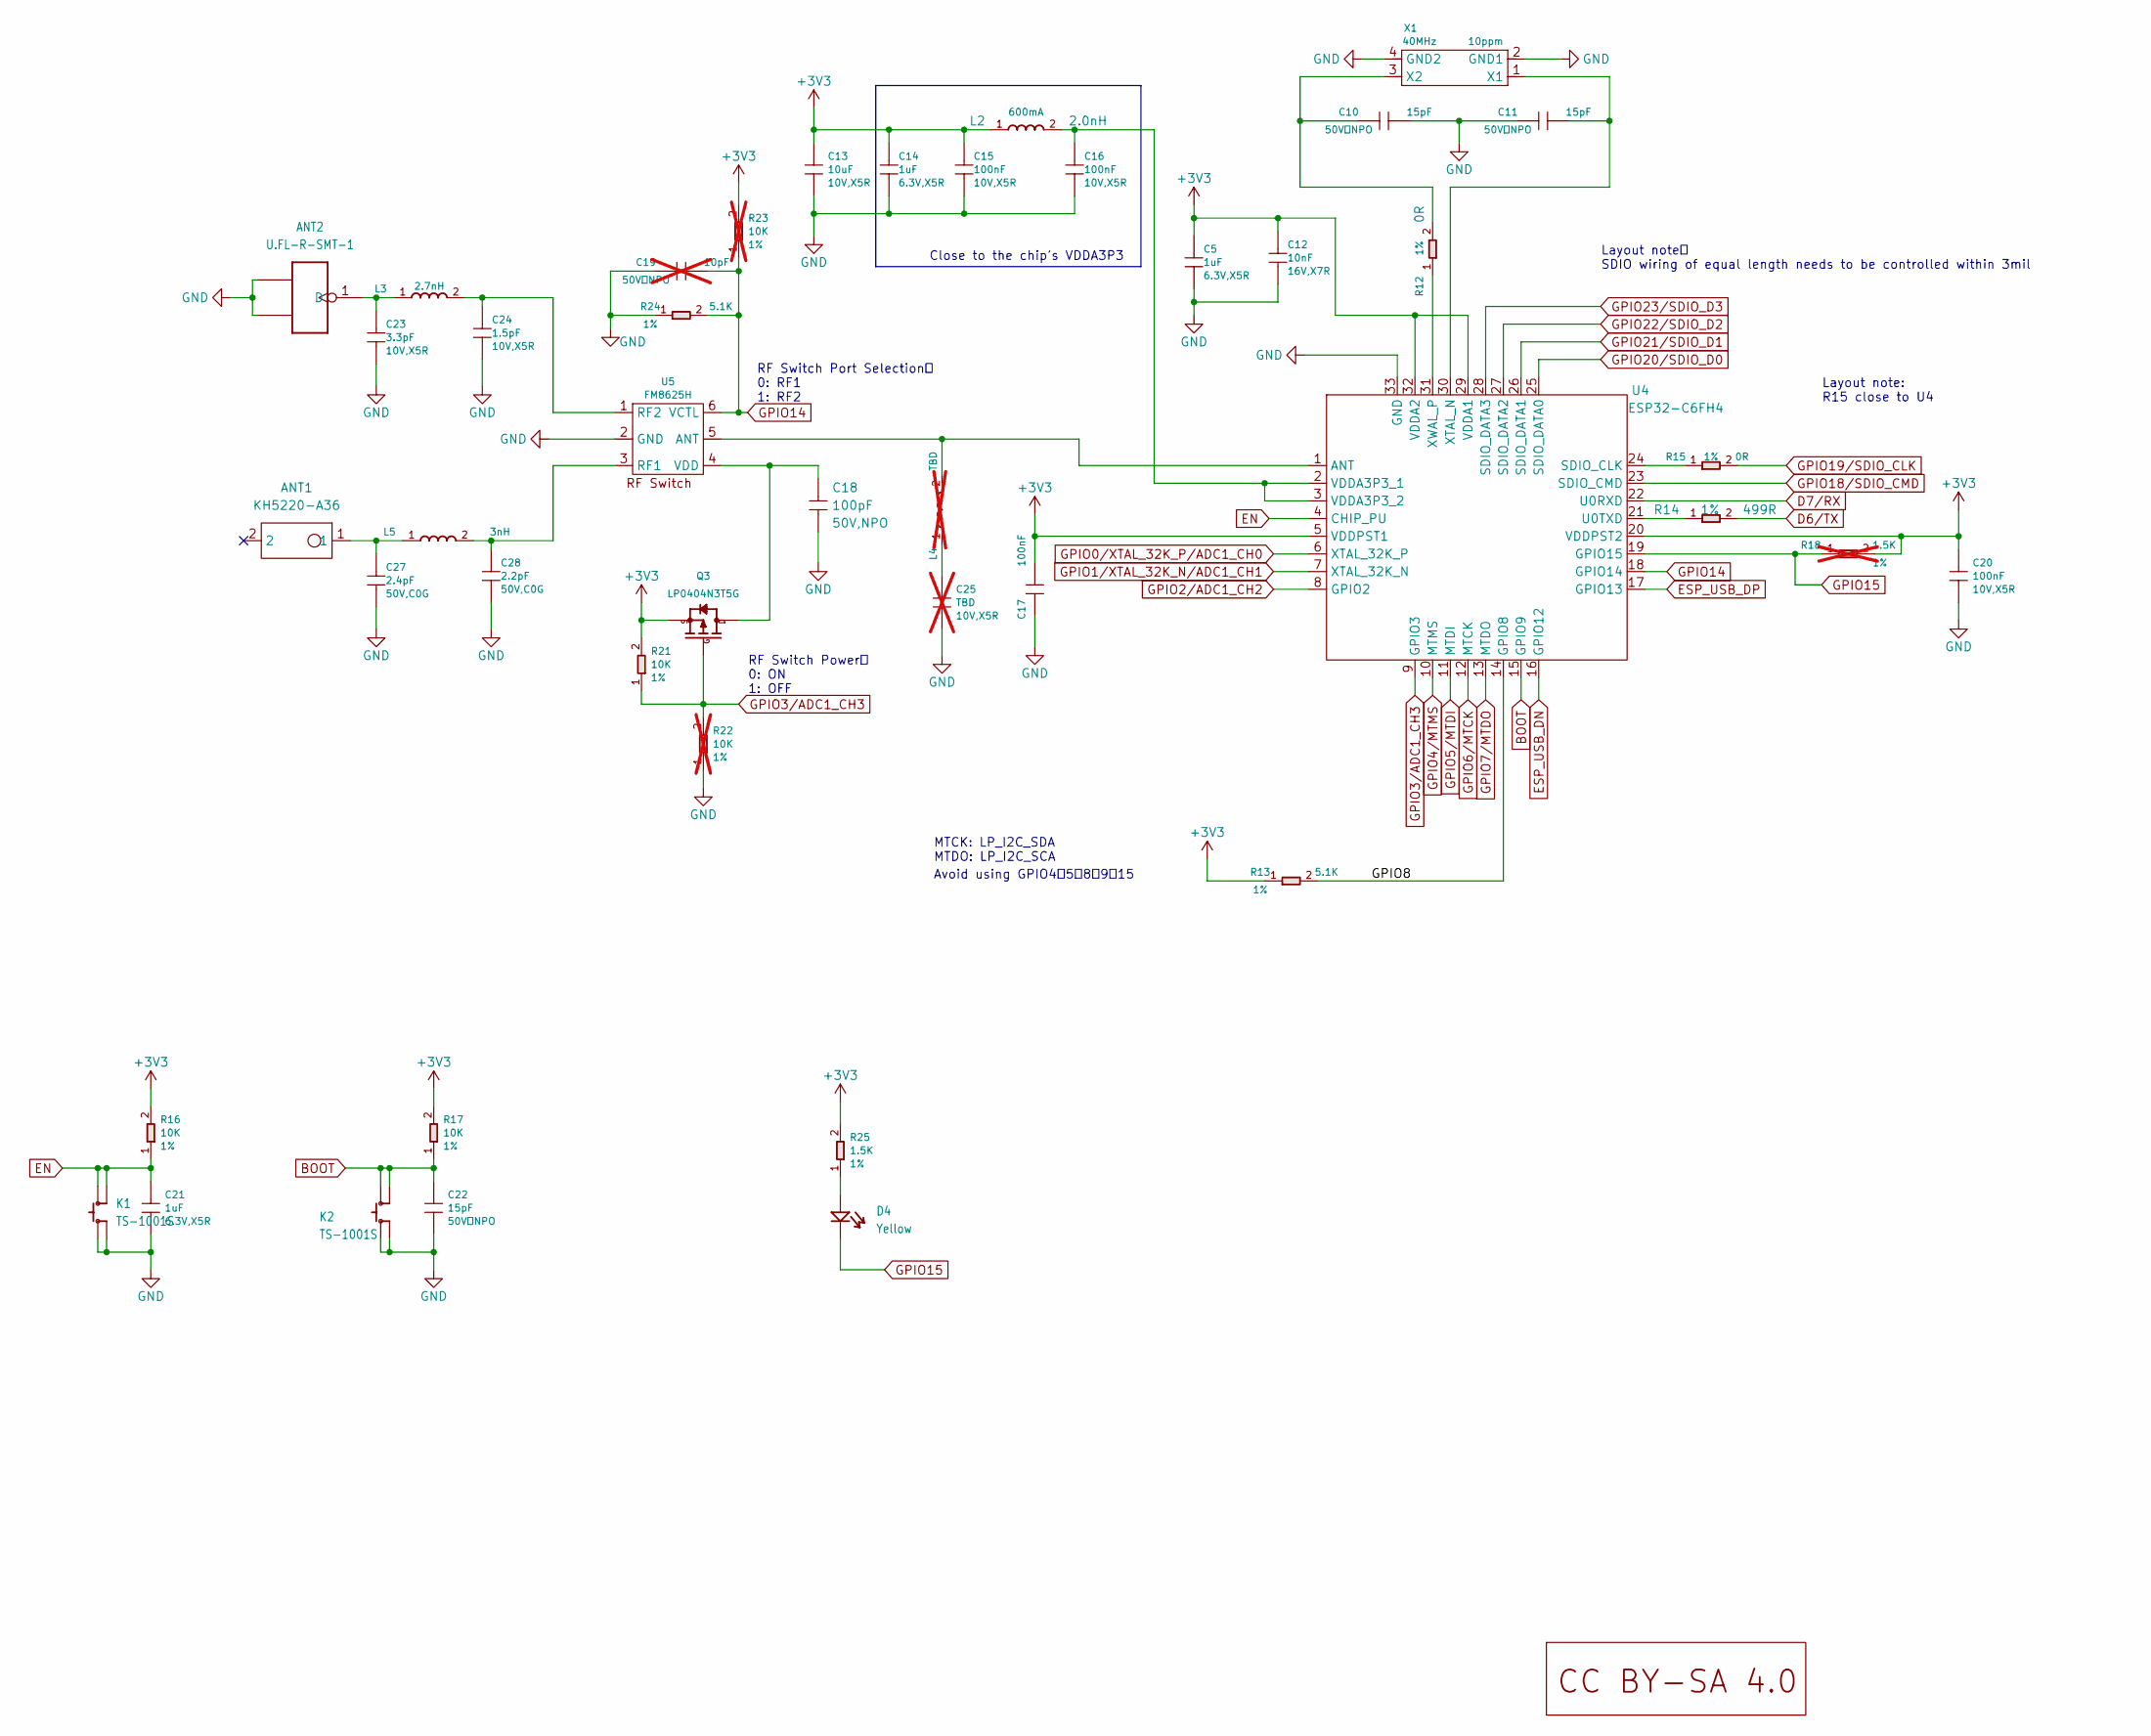
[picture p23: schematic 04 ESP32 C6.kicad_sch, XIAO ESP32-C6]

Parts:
ANT1: KH5220-A36; ANT2P-5.2x2x1.1MM; MPN KH5220-A36
ANT2: U.FL-R-SMT-1; U-FL3P-SMD-2.6X2.6X1.0MM; MPN U.FL-R-SMT-1
C5, C14, C21: 1uF; C0201; Voltage Rating 6.3V,X5R; MPN CC0201MRX5R5BB105
C10, C11, C22: 15pF; C0201; Voltage Rating 50V，NPO; MPN CC0201JRNPO9BN150
C12: 10nF; C0201; Voltage Rating 16V,X7R; MPN CC0201KRX7R7BB103
C13: 10uF; C0402; Voltage Rating 10V,X5R; MPN CC0402MRX5R6BB106
C15, C16, C17, C20: 100nF; C0201; Voltage Rating 10V,X5R; MPN CC0201KRX5R6BB104
C18: 100pF; C0201; Voltage Rating 50V,NPO; MPN CC0201JRNPO9BN101
C19: 10pF; C0201; Voltage Rating 50V，NPO; MPN CC0201JRNPO8BN100; not fitted
C23: 3.3pF; C0201; Voltage Rating 10V,X5R; MPN CQ0201BRNPO8BN3R3
C24: 1.5pF; C0201; Voltage Rating 10V,X5R; MPN CC0201BRNPO9BN1R5
C25: TBD; C0201; Voltage Rating 10V,X5R; Part Type Ceramic; not fitted
C27: 2.4pF; C0201; Voltage Rating 50V,C0G; MPN GRM0335C1H2R4BA01D
C28: 2.2pF; C0201; Voltage Rating 50V,C0G; MPN GRM0335C1H2R2BA01D
D4: Yellow; LED-0402; MPN 16-213/Y2C-AN2Q1B/3T
K1, K2: TS-1001S; SW4-SMD-2.8-2.6X1.6X0.53MM; MPN TS-1001S
L2: 2.0nH; L0201; Rating 600mA; MPN LQP03HQ2N0B02D
L3: 2.7nH; L0201; MPN LQP03TN2N7B02D
L4: TBD; L0201; Part Type L; not fitted
L5: 3nH; L0201; MPN LQP03TN3N0B02D
Q3: LP0404N3T5G; PMOS_1.0X0.6X0.35MM; MPN LP0404N3T5G
R12, R15: 0R; R0201; Power Rating 1%; MPN RC0201FR-070RL
R13, R24: 5.1K; R0201; Power Rating 1%; MPN RC0201FR-075K1L
R14: 499R; R0201; Power Rating 1%; MPN RC0201FR-07499RL
R16, R17, R21: 10K; R0201; Power Rating 1%; MPN RC0201FR-0710KL
R18: 1.5K; R0201; Power Rating 1%; MPN RC0201FR-071K5L; not fitted
R22, R23: 10K; R0201; Power Rating 1%; MPN RC0201FR-0710KL; not fitted
R25: 1.5K; R0201; Power Rating 1%; MPN RC0201FR-071K5L
U4: ESP32-C6FH4; QFN32-0.5-5X5MM; MPN ESP32-C6FH4
U5: FM8625H; DFN6-0.4-1.1X0.7X0.45MM; MPN FM8625H
U10: LOGO_CC_BY-SA_4.0
X1: 40MHz; X4-SMD-1.6X1.2MM; Rating 10ppm; MPN CJ17-400001010B20

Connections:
+3V3: C5.1, C12.1, C13.1, C14.1, C15.1, C17.1, C20.1, L2.1, Q3.2 (S), R13.1, R16.2, R17.2, R18.2, R21.2, R23.2, R25.2, U4.5 (VDDPST1), U4.20 (VDDPST2), U4.29 (VDDA1), U4.32 (VDDA2); also elsewhere on the board
/04 ESP32 C6/GPIO8: R13.2, U4.14 (GPIO8)
BOOT: C22.1, K2.3 (B0), K2.4 (B1), R17.1, U4.15 (GPIO9); also elsewhere on the board
D6/TX: R14.2; also elsewhere on the board
D7/RX: U4.22 (U0RXD); also elsewhere on the board
EN: C21.1, K1.3 (B0), K1.4 (B1), R16.1, U4.4 (CHIP_PU); also elsewhere on the board
ESP_USB_DN: U4.16 (GPIO12); also elsewhere on the board
ESP_USB_DP: U4.17 (GPIO13); also elsewhere on the board
GND: ANT2.2 (GND1), ANT2.3 (GND2), C5.2, C10.2, C11.1, C12.2, C13.2, C14.2, C15.2, C16.2, C17.2, C18.2, C19.1, C20.2, C21.2, C22.2, C23.2, C24.2, C25.2, C27.2, C28.2, K1.1 (A0), K1.2 (A1), K2.1 (A0), K2.2 (A1), R22.1, R24.1, U4.33 (GND), U5.2 (GND), X1.2 (GND1), X1.4 (GND2); also elsewhere on the board
GPIO0/XTAL_32K_P/ADC1_CH0: U4.6 (XTAL_32K_P); also elsewhere on the board
GPIO1/XTAL_32K_N/ADC1_CH1: U4.7 (XTAL_32K_N); also elsewhere on the board
GPIO2/ADC1_CH2: U4.8 (GPIO2); also elsewhere on the board
GPIO3/ADC1_CH3: Q3.1 (G), R21.1, R22.2, U4.9 (GPIO3)
GPIO4/MTMS: U4.10 (MTMS); also elsewhere on the board
GPIO5/MTDI: U4.11 (MTDI); also elsewhere on the board
GPIO6/MTCK: U4.12 (MTCK); also elsewhere on the board
GPIO7/MTDO: U4.13 (MTDO); also elsewhere on the board
GPIO14: C19.2, R23.1, R24.2, U4.18 (GPIO14), U5.6 (VCTL)
GPIO15: D4.2 (-), R18.1, U4.19 (GPIO15)
GPIO18/SDIO_CMD: U4.23 (SDIO_CMD); also elsewhere on the board
GPIO19/SDIO_CLK: R15.2; also elsewhere on the board
GPIO20/SDIO_D0: U4.25 (SDIO_DATA0); also elsewhere on the board
GPIO21/SDIO_D1: U4.26 (SDIO_DATA1); also elsewhere on the board
GPIO22/SDIO_D2: U4.27 (SDIO_DATA2); also elsewhere on the board
GPIO23/SDIO_D3: U4.28 (SDIO_DATA3); also elsewhere on the board
unnamed: ANT1.1, C27.1, L5.1
unnamed: ANT2.1 (D), C23.1, L3.1
unnamed: C25.1, L4.1
unnamed: D4.1 (+), R25.1
unnamed: C18.1, Q3.3 (D), U5.4 (VDD)
unnamed: L4.2, U4.1 (ANT), U5.5 (ANT)
unnamed: R15.1, U4.24 (SDIO_CLK)
unnamed: R14.1, U4.21 (U0TXD)
unnamed: C16.1, L2.2, U4.2 (VDDA3P3_1), U4.3 (VDDA3P3_2)
unnamed: C11.2, U4.30 (XTAL_N), X1.1 (X1)
unnamed: R12.1, U4.31 (XWAL_P)
unnamed: C28.1, L5.2, U5.3 (RF1)
unnamed: C24.1, L3.2, U5.1 (RF2)
unnamed: C10.1, R12.2, X1.3 (X2)

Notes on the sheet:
Avoid using GPIO4、5、8、9、15
RF Switch Power： 0: ON 1: OFF
Layout note: R15 close to U4
Close to the chip's VDDA3P3
Layout note： SDIO wiring of equal length needs to be controlled within 3mil
RF Switch Port Selection： 0: RF1 1: RF2
MTCK: LP_I2C_SDA MTDO: LP_I2C_SCA

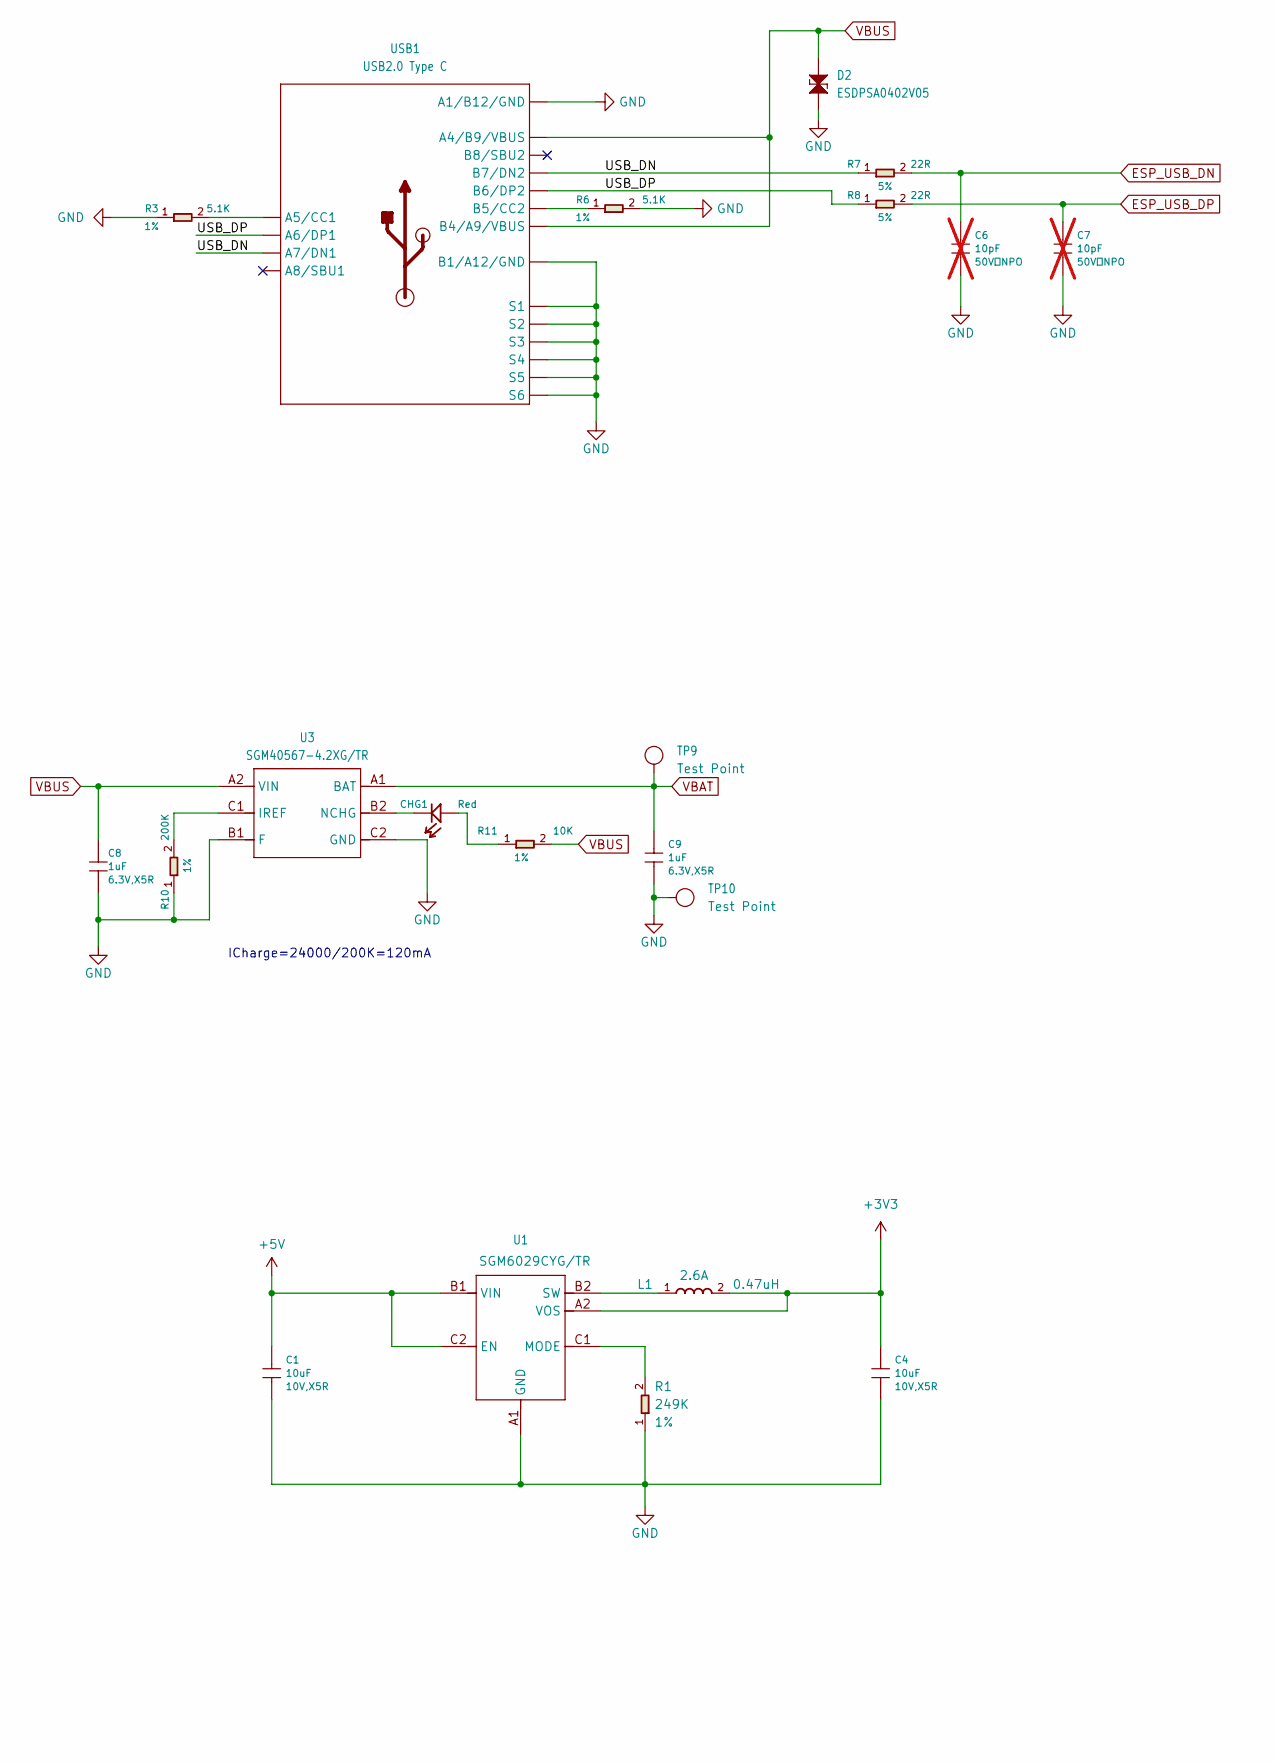
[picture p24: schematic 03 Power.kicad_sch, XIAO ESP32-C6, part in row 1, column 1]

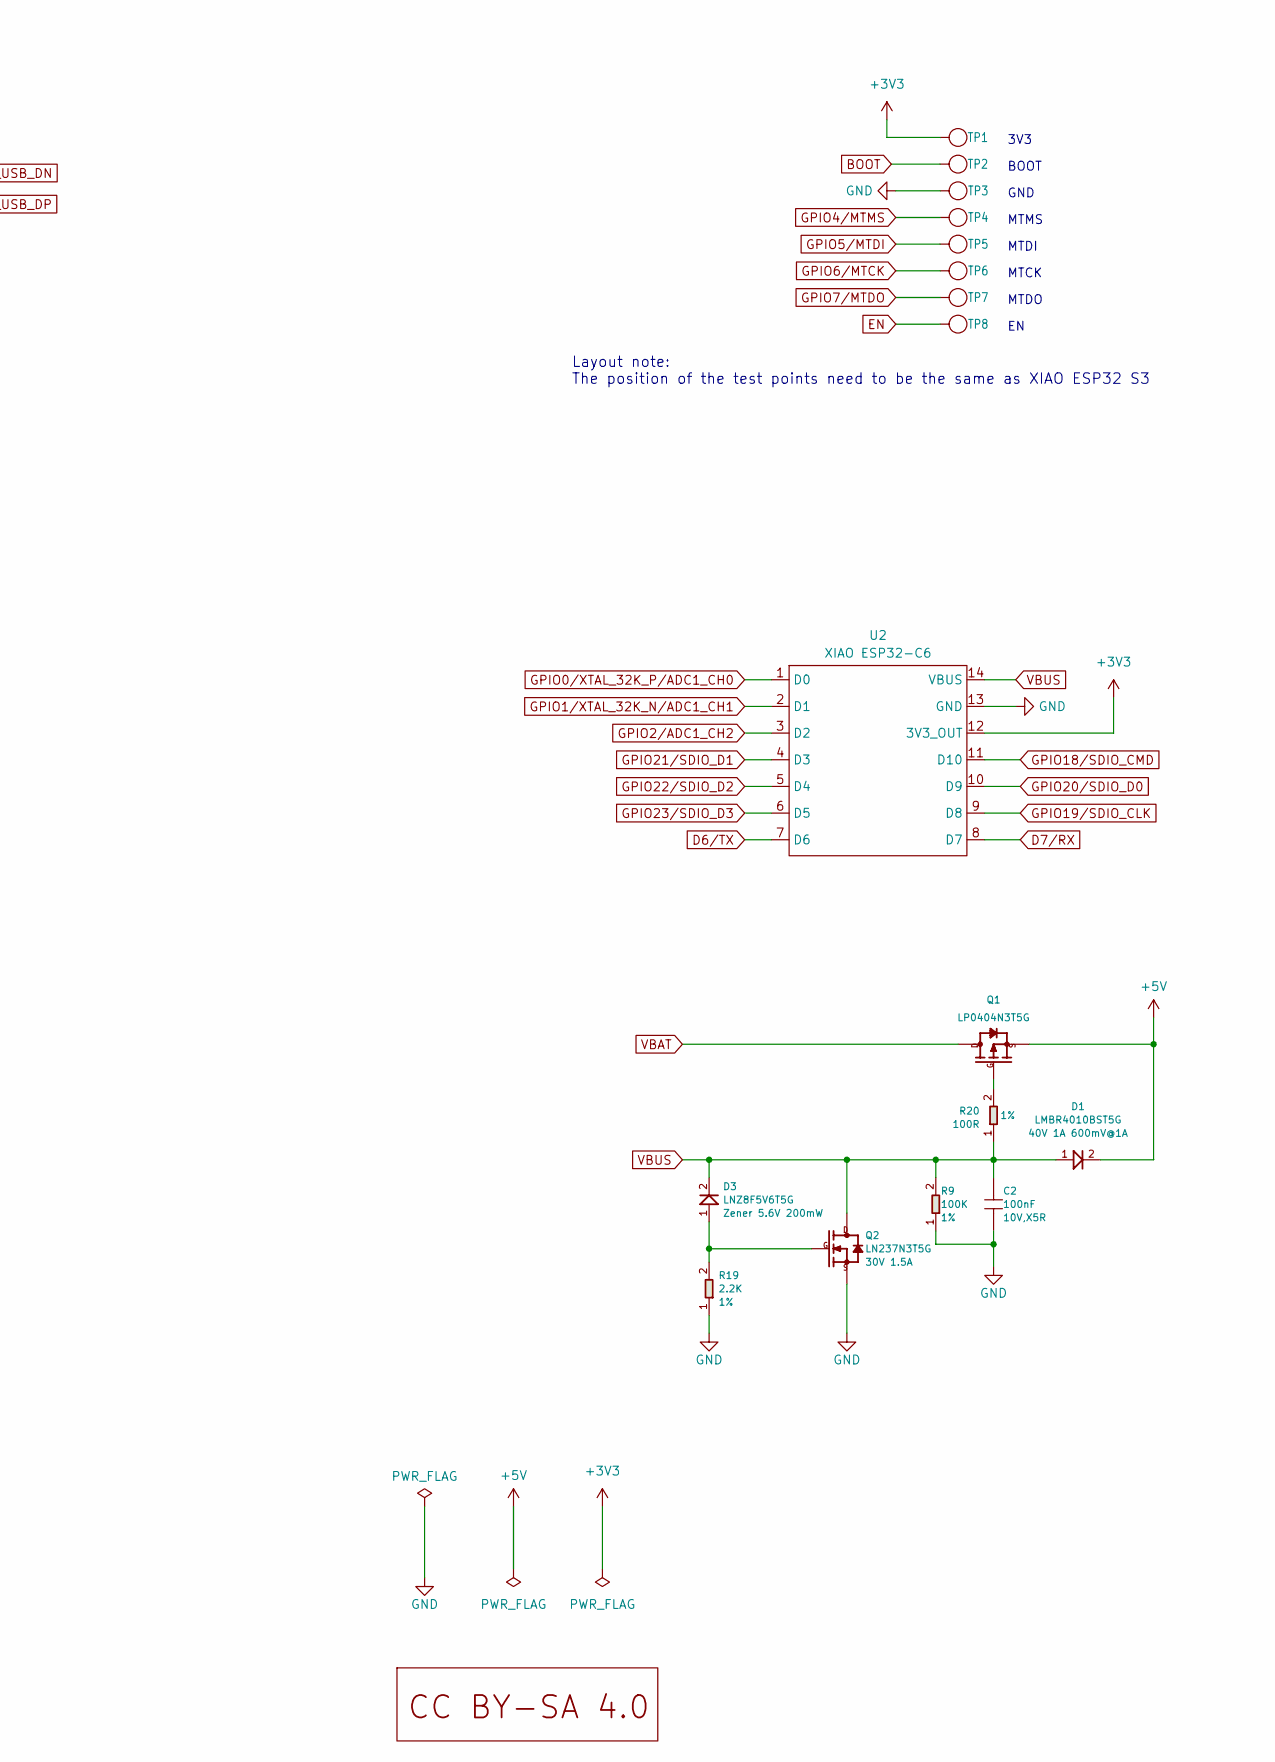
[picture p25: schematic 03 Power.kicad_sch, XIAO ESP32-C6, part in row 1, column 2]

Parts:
C1, C4: 10uF; C0402; Voltage Rating 10V,X5R; MPN CC0402MRX5R6BB106
C2: 100nF; C0201; Voltage Rating 10V,X5R; MPN CC0201KRX5R6BB104
C6, C7: 10pF; C0201; Voltage Rating 50V，NPO; MPN CC0201JRNPO8BN100; not fitted
C8, C9: 1uF; C0201; Voltage Rating 6.3V,X5R; MPN CC0201MRX5R5BB105
CHG1: Red; LED-0402; MPN BL-HUB37A-AV-TRB
D1: LMBR4010BST5G; DFN1006-2L; Rating 40V 1A 600mV@1A; MPN LMBR4010BST5G
D2: ESDPSA0402V05; ESD-0402; MPN ESDPSA0402V05
D3: LNZ8F5V6T5G; DFN1006-2L; Rating Zener 5.6V 200mW; MPN LNZ8F5V6T5G
L1: 0.47uH; L0603; Rating 2.6A; MPN TFM160808ALC-R47MTAA
Q1: LP0404N3T5G; PMOS_1.0X0.6X0.35MM; MPN LP0404N3T5G
Q2: LN237N3T5G; PMOS_1.0X0.6X0.35MM; Rating 30V 1.5A; MPN LN237N3T5G
R1: 249K; R0201; Power Rating 1%; MPN RC0201FR-07249KL
R3, R6: 5.1K; R0201; Power Rating 1%; MPN RC0201FR-075K1L
R7, R8: 22R; R0201; Power Rating 5%; MPN RC0201JR-0722RL
R9: 100K; R0201; Power Rating 1%; MPN RC0201FR-07100KL
R10: 200K; R0201; Power Rating 1%; MPN RC0201FR-07200KL
R11: 10K; R0201; Power Rating 1%; MPN RC0201FR-0710KL
R19: 2.2K; R0201; Power Rating 1%; MPN RC0201FR-072K2L
R20: 100R; R0201; Power Rating 1%; MPN RC0201FR-07100RL
TP1, TP2, TP3, TP4, TP5, TP6, TP7, TP8: Test Point; TP-D45MIL; Part Type Test Point
TP9, TP10: Test Point; TP-80X40MIL; Part Type Test Point
U1: SMD IC PMIC;DCDC Buck-ADJ-1A,Vin 1.95V to 5.5V,Vo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; BGA6-0.35-0.745X10.95X0.4MM; MPN SGM6029CYG/TR
U2: XIAO ESP32-C6; XIAO-Add-On
U3: SGM40567-4.2XG/TR; WLCSP-0.4-0.92X1.16X0.4MM; MPN SGM40567-4.2XG/TR
U9: LOGO_CC_BY-SA_4.0
USB1: USB2.0 Type C; USB2.0-TYPE-C; MPN UBF31-0171

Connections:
+3V3: C4.1, L1.2, TP1.1 (T), U1.A2 (VOS), U2.12 (3V3); also elsewhere on the board
+5V: C1.1, D1.2, Q1.2 (S), U1.B1 (VIN), U1.C2 (EN)
/03 Power/USB_DN: R7.1, USB1.A7 (A7/DN1), USB1.B7 (B7/DN2)
/03 Power/USB_DP: R8.1, USB1.A6 (A6/DP1), USB1.B6 (B6/DP2)
BOOT: TP2.1 (T); also elsewhere on the board
D6/TX: U2.7 (PB08_A6_D6_TX); also elsewhere on the board
D7/RX: U2.8 (PB09_A7_D7_RX); also elsewhere on the board
EN: TP8.1 (T); also elsewhere on the board
ESP_USB_DN: C6.1, R7.2; also elsewhere on the board
ESP_USB_DP: C7.1, R8.2; also elsewhere on the board
GND: C1.2, C2.2, C4.2, C6.2, C7.2, C8.2, C9.2, D2.1, Q2.2 (S), R1.1, R3.1, R6.2, R9.1, R10.1, R19.1, TP3.1 (T), TP10.1 (T), U1.A1 (GND), U2.13 (GND), U3.B1 (F), U3.C2 (GND), USB1.A1_B12 (A1/B12/GND), USB1.B1_A12 (B1/A12/GND), USB1.S1, USB1.S2, USB1.S3, USB1.S4, USB1.S5, USB1.S6; also elsewhere on the board
GPIO0/XTAL_32K_P/ADC1_CH0: U2.1 (PA02_A0_D0); also elsewhere on the board
GPIO1/XTAL_32K_N/ADC1_CH1: U2.2 (PA4_A1_D1); also elsewhere on the board
GPIO2/ADC1_CH2: U2.3 (PA10_A2_D2); also elsewhere on the board
GPIO4/MTMS: TP4.1 (T); also elsewhere on the board
GPIO5/MTDI: TP5.1 (T); also elsewhere on the board
GPIO6/MTCK: TP6.1 (T); also elsewhere on the board
GPIO7/MTDO: TP7.1 (T); also elsewhere on the board
GPIO18/SDIO_CMD: U2.11 (PA6_A10_D10_MOSI); also elsewhere on the board
GPIO19/SDIO_CLK: U2.9 (PA7_A8_D8_SCK); also elsewhere on the board
GPIO20/SDIO_D0: U2.10 (PA5_A9_D9_MISO); also elsewhere on the board
GPIO21/SDIO_D1: U2.4 (PA11_A3_D3); also elsewhere on the board
GPIO22/SDIO_D2: U2.5 (PA8_A4_D4_SDA); also elsewhere on the board
GPIO23/SDIO_D3: U2.6 (PA9_A5_D5_SCL); also elsewhere on the board
unnamed: CHG1.1 (+), R11.1
unnamed: CHG1.2 (-), U3.B2 (NCHG)
unnamed: Q1.1 (G), R20.2
unnamed: D3.1, Q2.1 (G), R19.2
unnamed: R1.2, U1.C1 (MODE)
unnamed: L1.1, U1.B2 (SW)
unnamed: R10.2, U3.C1 (IREF)
unnamed: R3.2, USB1.A5 (A5/CC1)
unnamed: R6.1, USB1.B5 (B5/CC2)
VBAT: C9.1, Q1.3 (D), TP9.1 (T), U3.A1 (BAT)
VBUS: C2.1, C8.1, D1.1, D2.2, D3.2, Q2.3 (D), R9.2, R11.2, R20.1, U2.14 (5V), U3.A2 (VIN), USB1.A4_B9 (A4/B9/VBUS), USB1.B4_A9 (B4/A9/VBUS)

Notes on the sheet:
MTMS
MTDI
ICharge=24000/200K=120mA
GND
MTDO
Layout note: The position of the test points need to be the same as XIAO ESP32 S3
MTCK
BOOT
3V3

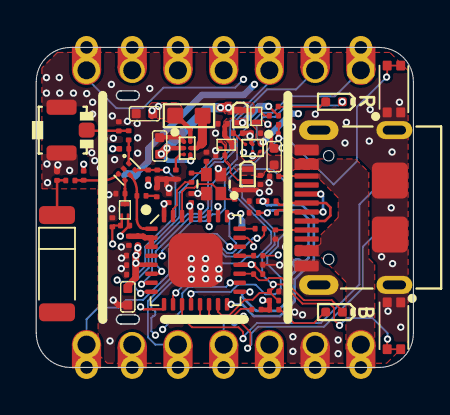
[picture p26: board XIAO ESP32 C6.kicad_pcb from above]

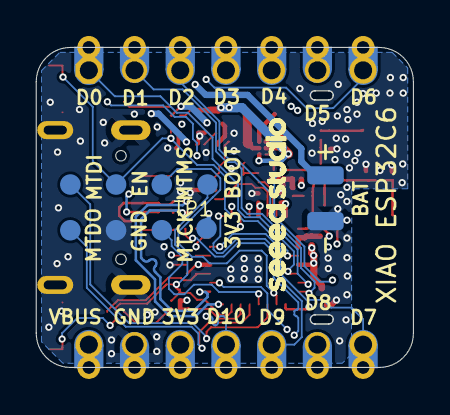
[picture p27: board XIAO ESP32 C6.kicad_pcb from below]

Board: 4 copper layers, 21.0 x 17.8 mm, 82 parts (10 on the bottom side), 53 nets.

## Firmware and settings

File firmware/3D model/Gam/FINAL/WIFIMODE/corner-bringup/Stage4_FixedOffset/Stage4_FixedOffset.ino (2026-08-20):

// ============================================================================
// TEENSY 4.1 + moteus-n1 x3 (CAN3, ids 1/2/3) + BMI270 IMU (SPI) —
// CORNER STAGE 4: FULL LAW + FIXED OFFSET (no live trim, no arm gate)
//                                                              [WiFi build]
// ============================================================================
// WiFi variant of ../../../../corner-bringup/Stage4_FixedOffset/. The control
// path -- corner table, estimator, full law, friction feedforward, kPhiOffset,
// the removed arm gate, the loosened velocity cap -- is copied VERBATIM and
// must not be retuned here. Retune in the USB sketch and re-copy. Everything
// this file adds is transport; see ../Stage1_CornerIDAndPulse_WiFi/ for the
// full rationale of the link layer, which is identical in all the corner
// bring-up WiFi stages.
//
// ---------------------------- COMMAND GRAMMAR -------------------------------
// This stage's own commands, ALL on their USB letters -- nothing was remapped:
//
//   a<0/1>    arm / disarm (NO arm gate -- see ARM GATE REMOVED below)
//   g<0..1>   gain scale
//   c         re-resolve corner
//   h<0/1>    halt
//
// WiFi-only controls live on letters this stage does not use:
//
//   k         keepalive no-op (feeds the link watchdog)
//   l<0/1>    link mode: l0 = telemetry on USB, l1 = telemetry on Serial1
//   d<N>      telemetry decimation, 1..100 (d2 = 250 Hz, d20 = 25 Hz)
//
// Unlike ../Stage4_AutoTrim_WiFi/ and ../Stage4_AutoTrim_RateFilter_WiFi/, NO
// letter had to move here. Those two had to remap 'x' (trim freeze) and 'k'
// (gKAdapt) because 'x' never reaches the Teensy -- the XIAO bridge consumes
// x0/x1 as ITS OWN mode switch and never relays them -- and because a bare
// "k" keepalive every 100 ms would parse as atof("") = 0.0 and silently zero
// the adaptation gain. This file retired the whole trim mechanism, so it has
// nothing bound to either letter and the collisions simply do not exist.
//
// ------------------------ LINK LOSS AUTO-DISARMS ----------------------------
// In WIFI mode, no line on Serial1 for kLinkTimeoutMs (3 s) force-disarms:
// over the radio the laptop is the operator's only disarm button, so a dead
// link must not leave the law running. Note what that means in THIS file
// specifically: the arm gate is gone (see below), so the link watchdog and
// kMaxTilt's 25 deg trip are the only automatic protections left. Read the
// ARM GATE REMOVED note with that in mind.
//
// ------------------------------- WIRING -------------------------------------
//   Teensy Serial1 TX1 (pin 1)  -> XIAO D7 (RX)
//   Teensy Serial1 RX1 (pin 0)  <- XIAO D6 (TX)
//   common GND
//
// ----------------------------------------------------------------------------
// Copy of Stage4_AutoTrim.ino with TWO mechanisms removed: (1) the live-
// adapting gTrim is replaced by a compile-time constant kPhiOffset, and
// (2) the arm gate (kArmGate, refusing "a1" unless already within 0.5 deg
// of equilibrium) is gone -- "a1" always arms now. Read Stage4_AutoTrim
// .ino's header first for why automatic trim exists and how it works --
// this file doesn't re-explain that mechanism, it retires it in favor of
// a known-good number.
//
// ---------------------------- WHAT AND WHY ---------------------------------
// kPhiOffset below (0.2624, 0.2265, -0.4830 deg) is NOT a guess or a
// snapshot -- it's the mean of Automatic Trim's own converged gTrim over
// a 132.41 s continuous armed hold (perfect_equilibrium_2.log, 2026-08-20),
// with per-axis std < 0.0012 deg over that whole window. That's the
// signature of a genuine fixed point, not a value still drifting: whatever
// residual COM/mounting error automatic trim was correcting for, it found
// it and stopped moving. Once a corner's offset is known this precisely,
// there's no more reason to re-derive it live every session -- hardcode
// it and remove the adaptation machinery (gTrim, gKAdapt, updateTrim(),
// applyTrimGuards(), the z/x/k serial commands) that existed to find it.
//
// If the cube's mounting changes (battery moved, a cable re-routed, a
// bolt re-torqued) this number goes stale -- that's the tradeoff for
// dropping live adaptation. Re-run Stage4_AutoTrim.ino, let it re-converge,
// and update kPhiOffset from the new result rather than assuming this one
// still holds.
//
// ---------------------------- ARM GATE REMOVED ------------------------------
// kArmGate (0.5 deg) is GONE from the 'a' command below -- "a1" arms
// unconditionally now, regardless of the cube's current tilt. This is a
// REAL SAFETY TRADEOFF, not just a convenience change, worth being
// explicit about:
//
// The Kp control law was derived by linearizing around this corner's
// equilibrium and is only VALIDATED for small angles (the simulation
// study's own recovery envelope tops out around 2.7-3.1 deg worst case,
// see Cube-Performance-Envelope-Results.md). Arming from a large initial
// tilt commands full-authority torque from OUTSIDE that validated
// envelope -- the arm gate existed specifically to prevent that. With it
// gone, the ONLY remaining backstop is kMaxTilt (25 deg, unchanged,
// still an automatic disarm-on-trip below in commandWheels()) -- which
// stops a runaway AFTER it's already happened, not before it starts.
//
// Removing the gate does NOT change what "close to the corner" means or
// make it safe to arm from far away -- it just stops the firmware from
// enforcing it. Placing the cube near the resolved equilibrium before
// sending "a1" is now an OPERATOR DISCIPLINE requirement instead of a
// code-enforced one. Physical stop/catch and a hand on the e-stop path
// matter more here than in Stage4_AutoTrim.ino, not less.
//
// STAGE 4 CHECKLIST — cube held by hand, gGainScale = 1.0:
//   Still place near the resolved corner's equilibrium before "a1" (see
//   the ARM GATE REMOVED note above -- this is now on you, not the code).
//   [ ] phi_x/y/z_deg in telemetry should already read close to zero at
//       rest, with no trim column doing any work -- that's the point of
//       hardcoding a validated offset instead of waiting for adaptation.
//   [ ] If phi at rest looks meaningfully different from what
//       perfect_equilibrium_2.log showed, something about the corner's
//       mounting has changed -- see the WHAT AND WHY note above, this
//       file's offset needs re-deriving, not trusting blindly.
//
// Checking phi at rest is the whole first checklist item, and 250 Hz is
// unreadable for it: "d20" (25 Hz) is the useful rate for that, "d2" puts it
// back for capture. Changing it re-prints the header, so the log stays
// self-describing.
//
// Velocity cap loosened (kMaxOmega, not literally removed) same as
// Stage4_AutoTrim.ino -- see that file's header for the full reasoning.
// Trips here are still LOOSE (hand-held) -- Stage 5 tightens to the real
// DISARM/OMEGA_CAP policy from cubli_gains.h.
// ============================================================================


// ----------------------------------------------------------------------------
// SECTION 1: LIBRARY INCLUDES
// ----------------------------------------------------------------------------

#include <MoteusTeensy.h>
#include <SPI.h>
#include "SparkFun_BMI270_Arduino_Library.h"


// ----------------------------------------------------------------------------
// SECTION 2: OBJECTS AND SETTINGS
// ----------------------------------------------------------------------------

ACAN_T4FD_Settings canSettings(1000000, DataBitRateFactor::x1);
MoteusTeensyCanFD canBus(ACAN_T4::can3, canSettings);

Moteus moteusX(canBus, []() { Moteus::Options options; options.id = 2; return options; }());
Moteus moteusY(canBus, []() { Moteus::Options options; options.id = 3; return options; }());
Moteus moteusZ(canBus, []() { Moteus::Options options; options.id = 1; return options; }());

BMI270 imu;
const uint8_t imuChipSelectPin = 10;
const uint32_t imuClockFrequency = 4000000;
const uint32_t kPeriodMs = 2;   // 500 Hz control loop -- NOT the telemetry rate

static uint32_t gNextSendMillis = 0;

static bool gHalted = false;
// Halting force-disarms (strict superset of "a0"), resuming does NOT re-arm.

// ---------------- Link mode + command channels ----------------
// Identical in all the corner bring-up WiFi stages -- fix a bug here and fix
// it in all of them.

// Emit telemetry every Nth control cycle. Non-const: "d<N>" writes it.
// This stage's line is 26 fields (~200 B): ~50 kB/s at 250 Hz, comfortable
// against the 1 Mbaud link, but the UDP hop is the real ceiling (~105
// lines/s measured in link-bringup Stage 6).
static uint8_t gTelemetryDecim = 2;   // 2 -> 250 Hz
static uint8_t gTelemetryCount = 0;
static const uint8_t kDecimMin = 1;
static const uint8_t kDecimMax = 100;

enum class LinkMode : uint8_t { USB = 0, WIFI = 1 };
static LinkMode gLinkMode = LinkMode::WIFI;   // boot default

const uint32_t kLinkBaud      = 1000000;   // must match TEENSY_LINK_BAUD in
                                            // the XIAO sketch
const uint32_t kLinkTimeoutMs = 3000;       // auto-disarm if WIFI mode and no
                                            // Serial1 line in this long
static uint32_t gLastSerial1RxMillis = 0;
static bool     gLinkAlive           = false;   // false at boot so the first
                                                 // packet from the laptop
                                                 // re-prints the header

// Small non-blocking line accumulator -- used for BOTH Serial and Serial1 so
// neither channel can ever stall loop() waiting on bytes that haven't
// arrived yet. Replaces the USB build's blocking readStringUntil('\n').
struct LineReader {
  char buf[64];
  uint8_t len = 0;

  bool poll(Stream& s, char* outLine, size_t outSize) {
    while (s.available()) {
      const char c = (char)s.read();
      if (c == '\n' || c == '\r') {
        if (len == 0) { continue; }   // swallow CRLF / blank artifacts
        buf[len] = '\0';
        const uint8_t copyLen = (len < outSize - 1) ? len : (uint8_t)(outSize - 1);
        memcpy(outLine, buf, copyLen);
        outLine[copyLen] = '\0';
        len = 0;
        return true;
      }
      if (len < sizeof(buf) - 1) { buf[len++] = c; }
      // else: line too long -- drop the overflow char, keep accumulating
      // until the terminator so we resync on the next line.
    }
    return false;
  }
};

static LineReader gUsbReader;
static LineReader gLinkReader;

// Boot/diagnostic sink: writes to USB and to the XIAO link at the same time.
// Only used outside the control path -- per-cycle telemetry goes to exactly
// one stream, chosen by gLinkMode.
class DualPrint : public Print {
 public:
  using Print::write;   // keep the base write(const char*) overload visible
  size_t write(uint8_t c) override {
    Serial.write(c);
    Serial1.write(c);
    return 1;
  }
  size_t write(const uint8_t* b, size_t n) override {
    Serial.write(b, n);
    Serial1.write(b, n);
    return n;
  }
};
static DualPrint gBoot;

// Where asynchronous console messages go -- the channel the operator is
// actually on.
static inline Stream& activeStream() {
  return (gLinkMode == LinkMode::WIFI) ? (Stream&)Serial1 : (Stream&)Serial;
}


// ----------------------------------------------------------------------------
// SECTION 2b: STATE ESTIMATION -- gam (unchanged from Stage 1-3)
// ----------------------------------------------------------------------------

static const float kG0 = 9.80665f;
static const float kGyroBias[3]    = { +0.002348f, -0.001140f, -0.000762f };
static const float kAccelOffset[3] = { -0.092282f, -0.196510f, +0.050664f };
static const float kAccelScale[3]  = {  0.991085f,  0.991035f,  1.003787f };

float theta1_deg = -30.0f;
float theta2_deg = 54.74f;
float theta3_deg = 45.0f;
float gMountDCM[3][3];

void updateMountingDCM() {
  const float k  = (float)DEG_TO_RAD;
  const float c1 = cosf(theta1_deg * k), s1 = sinf(theta1_deg * k);
  const float c2 = cosf(theta2_deg * k), s2 = sinf(theta2_deg * k);
  const float c3 = cosf(theta3_deg * k), s3 = sinf(theta3_deg * k);
  gMountDCM[0][0] =  c1*c3 - c2*s1*s3;
  gMountDCM[0][1] =  c3*s1 + c1*c2*s3;
  gMountDCM[0][2] =  s2*s3;
  gMountDCM[1][0] = -c1*s3 - c2*c3*s1;
  gMountDCM[1][1] =  c1*c2*c3 - s1*s3;
  gMountDCM[1][2] =  c3*s2;
  gMountDCM[2][0] =  s1*s2;
  gMountDCM[2][1] = -c1*s2;
  gMountDCM[2][2] =  c2;
}

// Takes the sink explicitly so the same check is readable over WiFi at boot.
void checkMountingDCMValid(Print& out) {
  const float (&C)[3][3] = gMountDCM;
  const float det = C[0][0]*(C[1][1]*C[2][2] - C[1][2]*C[2][1])
                   - C[0][1]*(C[1][0]*C[2][2] - C[1][2]*C[2][0])
                   + C[0][2]*(C[1][0]*C[2][1] - C[1][1]*C[2][0]);
  out.print("# mount DCM check: det="); out.print(det, 4);
  for (int i = 0; i < 3; ++i) {
    const float len = sqrtf(C[i][0]*C[i][0] + C[i][1]*C[i][1] + C[i][2]*C[i][2]);
    out.print("  |row"); out.print(i); out.print("|="); out.print(len, 4);
  }
  out.println();
}

void readIMURaw(BMI270& sensor, float aImu[3], float wImu[3]) {
  aImu[0] = (sensor.data.accelX * kG0 - kAccelOffset[0]) / kAccelScale[0];
  aImu[1] = (sensor.data.accelY * kG0 - kAccelOffset[1]) / kAccelScale[1];
  aImu[2] = (sensor.data.accelZ * kG0 - kAccelOffset[2]) / kAccelScale[2];
  wImu[0] = sensor.data.gyroX * (float)DEG_TO_RAD - kGyroBias[0];
  wImu[1] = sensor.data.gyroY * (float)DEG_TO_RAD - kGyroBias[1];
  wImu[2] = sensor.data.gyroZ * (float)DEG_TO_RAD - kGyroBias[2];
}

void rotateToBodyFrame(const float aImu[3], const float wImu[3],
                       float aBody[3], float wBody[3]) {
  for (int i = 0; i < 3; ++i) {
    wBody[i] = gMountDCM[i][0]*wImu[0] + gMountDCM[i][1]*wImu[1] + gMountDCM[i][2]*wImu[2];
    aBody[i] = gMountDCM[i][0]*aImu[0] + gMountDCM[i][1]*aImu[1] + gMountDCM[i][2]*aImu[2];
  }
}

static inline float norm3(const float v[3]) { return sqrtf(v[0]*v[0]+v[1]*v[1]+v[2]*v[2]); }
static inline void normalize3(float v[3]) {
  const float n = norm3(v);
  if (n > 1e-9f) { v[0] /= n; v[1] /= n; v[2] /= n; }
}
static inline void cross3(const float a[3], const float b[3], float out[3]) {
  out[0] = a[1]*b[2] - a[2]*b[1];
  out[1] = a[2]*b[0] - a[0]*b[2];
  out[2] = a[0]*b[1] - a[1]*b[0];
}
static inline float dot3(const float a[3], const float b[3]) {
  return a[0]*b[0] + a[1]*b[1] + a[2]*b[2];
}

float ghat[3] = { 0.0f, 0.0f, 1.0f };
float w_b[3]  = { 0.0f, 0.0f, 0.0f };
static float gGyroBiasBody[3] = { 0.0f, 0.0f, 0.0f };

void calibrateGyroBias(uint16_t n_samples) {
  float sum[3] = { 0.0f, 0.0f, 0.0f };
  for (uint16_t i = 0; i < n_samples; ++i) {
    imu.getSensorData();
    float aImu[3], wImu[3], aBody[3], wBody[3];
    readIMURaw(imu, aImu, wImu);
    rotateToBodyFrame(aImu, wImu, aBody, wBody);
    sum[0] += wBody[0]; sum[1] += wBody[1]; sum[2] += wBody[2];
    delay(2);
  }
  gGyroBiasBody[0] = sum[0]/n_samples;
  gGyroBiasBody[1] = sum[1]/n_samples;
  gGyroBiasBody[2] = sum[2]/n_samples;
}

static const float kP_FILT = 4.0f;   // HARD CLIFF between 6 and 7 -- do not raise
static const float kI_FILT = 0.5f;
static float bhat[3] = { 0.0f, 0.0f, 0.0f };
static bool gEstimatorInit = false;

void attitudeUpdate(const float a_imu[3], const float w_imu[3], float dt) {
  float aBody[3], wBodyRaw[3];
  rotateToBodyFrame(a_imu, w_imu, aBody, wBodyRaw);
  const float wRaw[3] = {
    wBodyRaw[0] - gGyroBiasBody[0],
    wBodyRaw[1] - gGyroBiasBody[1],
    wBodyRaw[2] - gGyroBiasBody[2],
  };

  float ga[3] = { aBody[0], aBody[1], aBody[2] };
  normalize3(ga);

  if (!gEstimatorInit) {
    ghat[0] = ga[0]; ghat[1] = ga[1]; ghat[2] = ga[2];
    gEstimatorInit = true;
    return;
  }

  float e[3];
  cross3(ghat, ga, e);
  const float wc[3] = { wRaw[0]-bhat[0], wRaw[1]-bhat[1], wRaw[2]-bhat[2] };
  float wxg[3]; cross3(wc, ghat, wxg);
  float exg[3]; cross3(e, ghat, exg);
  for (int i = 0; i < 3; ++i) { ghat[i] += dt * (-wxg[i] + kP_FILT * exg[i]); }
  normalize3(ghat);
  for (int i = 0; i < 3; ++i) { bhat[i] += kI_FILT * e[i] * dt; }   // PLUS
  for (int i = 0; i < 3; ++i) { w_b[i] = wRaw[i] - bhat[i]; }

  static int badCount = 0;
  if (dot3(ghat, ga) < 0.0f) {
    badCount++;
    if (badCount > 20) {
      ghat[0] = ga[0]; ghat[1] = ga[1]; ghat[2] = ga[2];
      bhat[0] = bhat[1] = bhat[2] = 0.0f;
      badCount = 0;
    }
  } else {
    badCount = 0;
  }
}


// ----------------------------------------------------------------------------
// SECTION 2c: CORNER CANDIDATE (resolved fresh here too)
// ----------------------------------------------------------------------------

struct CornerCandidate {
  const char* name;
  float gB[3];
  float Kp[3][9];   // rows = wheel X,Y,Z; cols = [phi(3) om(3) rho(3)]
  float placeOffsetDeg;
  float ellM;       // m, contact-to-COM lever arm -- NEW vs Stage4_FullLaw.ino,
                     // used only to convert a converged trim into an
                     // equivalent COM offset in mm for telemetry (Automatic
                     // Trim.md S4's "log trim continuously" guard).
};
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
void loop() {
  pollCommands();

  // Link watchdog -- the laptop is the operator's only disarm button in WiFi
  // mode. Enforced whenever WIFI mode is selected, even if the laptop has
  // never spoken (gLinkAlive still false) -- otherwise a USB "a1" with no
  // laptop would leave the law running. This matters more here than in the
  // AutoTrim builds: with the arm gate gone, it and kMaxTilt are the only
  // automatic protections left.
  if (gLinkMode == LinkMode::WIFI &&
      millis() - gLastSerial1RxMillis > kLinkTimeoutMs) {
    if (gArmed) {
      gArmed = false;
      gBoot.println("# DISARMED: link lost");
    }
    gLinkAlive = false;
  }

  if (gHalted) { return; }

  if (static_cast<int32_t>(millis() - gNextSendMillis) < 0) { return; }
  gNextSendMillis += kPeriodMs;

  const uint32_t time = millis();

  static uint32_t lastMicros = 0;
  static bool dtInitialized = false;
  const uint32_t nowMicros = micros();
  float dt = dtInitialized ? (nowMicros - lastMicros) * 1e-6f : kPeriodMs * 1e-3f;
  lastMicros = nowMicros;
  dtInitialized = true;
  if (dt <= 0.0f || dt > 0.5f) { dt = kPeriodMs * 1e-3f; }

  float aImu[3], wImu[3];
  imu.getSensorData();
  readIMURaw(imu, aImu, wImu);
  attitudeUpdate(aImu, wImu, dt);
  updateCornerProjection();

  const float rho[3] = {
    kAxisWheelSign[0] * moteusX.last_result().values.velocity * 2.0f * (float)PI,
    kAxisWheelSign[1] * moteusY.last_result().values.velocity * 2.0f * (float)PI,
    kAxisWheelSign[2] * moteusZ.last_result().values.velocity * 2.0f * (float)PI,
  };

  commandWheels(rho);
  // no updateTrim() call -- kPhiOffset is fixed, nothing to adapt each cycle

  // --- telemetry: decimated, and to Serial or Serial1 per gLinkMode ---
  // Every control cycle above ran in full; only the emission below is
  // throttled.
  if (++gTelemetryCount >= gTelemetryDecim) {
    gTelemetryCount = 0;
    printState(activeStream(), time, rho, gRhoLp, gLastTau, gLastTauCmd,
               gArmed, gGainScale);
  }
}   // end of loop()


// ============================================================================
// NOTES
// ----------------------------------------------------------------------------
// This file vs Stage4_AutoTrim.ino: identical control law, identical corner
// candidate table -- the difference is entirely in how phi's offset is
// sourced (compile-time constant here vs live adaptation there) and that
// the arm gate is gone. If something looks wrong here that isn't about
// either of those two things, check whether Stage4_AutoTrim.ino has the
// same problem before assuming this file's changes caused it.
//
// This file vs ../../../../corner-bringup/Stage4_FixedOffset/: transport
// only. The link layer (LineReader, DualPrint, watchdog, k/l/d) is the same
// one every corner bring-up WiFi stage uses, and no command letter had to
// move -- see the header for why this build escapes the x/k remapping the
// AutoTrim WiFi builds needed. Retune in the USB sketch, then re-copy.
//
// This file exists because Automatic Trim already did its job and found a
// stable, precise answer (perfect_equilibrium_2.log) -- it is a
// consequence of trust in that mechanism, not a replacement for it.
// Stage4_AutoTrim.ino remains the way to (re-)derive kPhiOffset if the
// corner's mounting ever changes; this file is for running with an
// already-known-good value without paying the adaptation/convergence time
// every session, and without the arm gate blocking arming while iterating.
//
// Next steps:
//   - Port the same two changes (fixed offset + no arm gate) to the rate-
//     filter variant -- see Stage4_FixedOffset_RateFilter.ino.
//   - If this offset is trusted across multiple sessions/days, it's a
//     candidate for promoting into cubli_gains.h's per-corner table
//     directly (as a per-corner phi bias) rather than living only here.
//   - Re-derive kPhiOffset (re-run Stage4_AutoTrim.ino, let it converge,
//     take the new mean) after ANY mechanical change to this corner --
//     battery moved, cable re-routed, bolt re-torqued. This file has no
//     way to detect that its offset has gone stale on its own.
// ============================================================================

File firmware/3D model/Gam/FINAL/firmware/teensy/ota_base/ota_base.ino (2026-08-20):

// ============================================================================
// TEENSY 4.1 -- MODE STATE MACHINE + WIRELESS (OTA) FLASHING  -- TEMPLATE
// ============================================================================
// Companion to ../../xiao/console_host/console_host.ino and the web
// console it serves. This is a TEMPLATE, and the word is meant literally:
//
//   WHAT IS REAL AND WORKS AS-IS
//     - the Serial1 link layer, watchdog and command grammar;
//     - the BMI270 read path, mounting DCM and the gam attitude estimator,
//       transplanted verbatim from CornerBalance_WiFi.ino (SECTION 2b);
//     - corner and edge pivot resolution and projection, so |phi| / theta are
//       real numbers you can watch on the console the moment you flash this;
//     - the IDLE / EDGE / CORNER state machine and its interlocks;
//     - telemetry in both existing wire formats, plus the '#H' health line;
//     - the whole OTA pipeline: hex parsing, checksum validation, staging into
//       the FlasherX buffer and flash_move().
//
//   WHAT IS A STUB AND WILL NOT BALANCE ANYTHING
//     - the control laws. cornerControlStep() and edgeControlStep() command
//       ZERO torque and only query the controllers. The gain tables that go
//       with them (kCorners[].Kp, kCandidates[].K) are deliberately NOT copied
//       here either -- they belong with the law.
//
// Flashed as-is this is a safe, useful instrument: real attitude telemetry,
// real wheel speeds, real battery voltage, working E-STOP, working OTA. It
// just never commands torque. See TRANSPLANTING A CONTROL LAW at the bottom.
//
// !! NOTHING IN THIS FILE HAS BEEN VALIDATED ON HARDWARE. !!
// The corner and edge WiFi builds themselves are still marked unvalidated in
// their own headers. Treat the first run as a bring-up: cube on the bench,
// one hand on it, E-STOP in reach.
//
// ---------------------------------------------------------------------------
// FLASHERX SETUP -- REQUIRED, ONE TIME
// ---------------------------------------------------------------------------
// FlasherX is not an Arduino library; it is source you copy into the sketch
// folder. From https://github.com/joepasquariello/FlasherX, copy into THIS
// directory (next to this .ino):
//
//     FlashTxx.c        FlashTxx.h
//
// FXUtil.cpp / FXUtil.h are NOT needed and should NOT be copied. Their
// update_firmware() is an interactive routine that prompts "enter %d to flash
// or 0 to abort" on a Stream and waits for a typed reply -- unusable across a
// WiFi bridge. This file drives the stable primitives directly instead
// (firmware_buffer_init / flash_write_block / check_flash_id / flash_move) and
// carries its own Intel HEX parser, which is also where the per-record
// checksum validation happens.
//
// ---------------------------------------------------------------------------
// WHAT YOU CAN AND CANNOT FLASH OVER THE AIR
// ---------------------------------------------------------------------------
// check_flash_id() searches the staged image for the literal string
// "fw_teensy41", which FlashTxx.c puts into any sketch that compiles it in.
// So THE IMAGE YOU UPLOAD MUST ITSELF INCLUDE FLASHERX. Upload a sketch built
// without it and the commit is refused -- which is the check doing its job,
// because that image would also be the last one you could ever flash
// wirelessly. Every OTA-able build needs FlashTxx.c in its sketch folder.
//
// ---------------------------------------------------------------------------
// COMMAND GRAMMAR
// ---------------------------------------------------------------------------
//   m<0/1/2> mode: 0 IDLE, 1 EDGE, 2 CORNER. Always disarms and stops wheels.
//   a<0/1>   arm / disarm. a1 passes the tilt gate and is refused in IDLE.
//   g<0..1>  gain scale
//   c / e    re-resolve the corner / edge pivot
//   z<0/1>   tare / clear the corner phi offset
//   o<deg>   set the edge phi offset
//   p<0/1>   halt / resume
//   t<0/1>   link mode: 0 USB, 1 WiFi (default 1)
//   h | k    no-op keepalive
//   u1 / u? / u2 / u0    OTA: begin / probe / commit / abort  (see SECTION 6)
//
// 'h' is a KEEPALIVE here, not halt -- same choice CornerBalance_WiFi.ino made
// and for the same reason: the link heartbeat is a bare letter sent ten times
// a second, and binding halt to it would halt the cube continuously.
//
// Wiring (unchanged):
//   Teensy Serial1 TX1 (pin 1)  -> XIAO D7 (RX)
//   Teensy Serial1 RX1 (pin 0)  <- XIAO D6 (TX)
//   Common GND.
// ============================================================================

#if !__has_include("FlashTxx.h")
#error "FlasherX missing. Copy FlashTxx.c and FlashTxx.h from https://github.com/joepasquariello/FlasherX into this sketch folder. See the FLASHERX SETUP note at the top of this file."
#endif

#include <MoteusTeensy.h>
#include <SPI.h>
#include "SparkFun_BMI270_Arduino_Library.h"

// FlashTxx.h declares C functions but does NOT wrap itself in extern "C", so
// the wrap has to happen here or every symbol comes out C++-mangled and the
// link fails. This is the pattern FlasherX's own example sketch uses.
extern "C" {
  #include "FlashTxx.h"
}


// ----------------------------------------------------------------------------
// SECTION 0: CONFIGURATION
// ----------------------------------------------------------------------------

// Set to 1 ONLY after transplanting a real control law into SECTION 4. While
// this is 0, commandWheels() issues query-only frames and never commands
// torque, no matter what mode is selected or whether the cube is armed.
#define CONTROL_LAW_TRANSPLANTED 0

#define SERIALMONITORMODE 0
#define PLOTMODE 1
#define TELEMETRY_MODE PLOTMODE

// Serial1 <-> XIAO. MUST match TEENSY_LINK_BAUD in console_host.ino.
// 1 Mbaud, not 115200: a 21-field corner line is ~170 B at 250 Hz = ~340
// kbit/s, which does not fit in 115200 -- Serial1 writes would start blocking
// inside the 2 ms control cycle. See CornerBalance_WiFi.ino:33 for the full
// budget. A mismatch between the two sketches is silent and looks like a dead
// link, so change both together or neither.
const uint32_t kLinkBaud = 1000000;

// Auto-disarm if WIFI mode and no Serial1 line for this long. The XIAO's
// keepalive is 100 ms and is itself gated on the browser still pinging, so
// this is the last link in an end-to-end deadman chain -- see the long note
// in console_host.ino.
const uint32_t kLinkTimeoutMs = 300;

const uint32_t kPeriodMs = 2;            // 500 Hz control loop
static const uint8_t kTelemetryDecim = 2;  // -> 250 Hz on the wire
const uint32_t kHealthIntervalMs = 500;  // '#H' battery/mode/armed line
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

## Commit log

2026-08-04 Add dynamics derivations, electronics, BOM, and 2D panel simulation
    Bring in the Cubli project's equations of motion (3D corner-balancing
    and its 2D/1D edge-balancing reduction), electronics design and KiCad
    project, BOM and component reference notes, and the 2D nonlinear panel
    simulation (MATLAB + Simulink) with its four validation reports
    (saturation, discrete loop, IMU lever arm, friction), sourced from
    Obsidian notes and local MATLAB/KiCad work.
    [01 Descriptions.kicad_sch, 02 Block Diagram.kicad_sch, 03 Power.kicad_sch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]
2026-08-08 Add Stage 0-5 panel bring-up firmware
    Staged Arduino IDE bring-up sequence for the Teensy 4.1 + moteus-n1 +
    BMI270 panel rig, from estimator-only observation through closed-loop
    balancing with rails/e-stop. Confirmed working end to end on hardware.
    Includes two hardware-confirmed bug fixes, documented in the implementation
    notes:
    - SetPosition()'s default wire format silently drops every Command field
    except position/velocity, so torque-mode commands never reached the
    moteus until a custom Format was passed explicitly.
    - The wheel's physical mounting convention was backwards relative to the
    LQR model's sign convention (Stage 1 sign check 4) -- fixed with a
    single kWheelSign constant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
    [Stage1_OpenLoopTorque.ino, Stage2_DampingOnly.ino, Stage3_PositionDamping.ino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]
2026-08-08 Add firmware/README.md and 2D->3D lessons-learned doc
    Index the firmware/ folder now that it holds a real target (2D model/
    panel-bringup/, confirmed working end to end on hardware) and will grow a
    3D model/ sibling.
    The lessons-learned doc condenses the panel bring-up into what's worth
    carrying into the cube firmware: the two real bugs found (moteus
    SetPosition()'s default Format silently drops every Command field except
    position/velocity; the wheel's physical mounting sign convention was
    backwards relative to the LQR model and needed a hardware-boundary fix,
    not a gains change), the estimator/actuator gotchas (complementary filter
    tuning, real stiction thresholds, gain-vs-actuator-capabil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
2026-08-08 Stage4: widen kMaxTilt/kMaxOmega for full-envelope testing
    kMaxTilt 8 deg -> 30 deg, kMaxOmega 40 -> 600 rad/s (still well under the
    883 rad/s no-load omega_max). Confirmed working on hardware across the
    wider envelope. kTauMax and kTaperStart untouched.
    Merged on top of the existing TELEMETRY_MODE selector and halt command
    rather than replacing the file, so neither gets lost.
2026-08-08 Stage4: overwrite with local file exactly, per explicit request
    Supersedes the previous commit on this branch (which had merged the wider
    kMaxTilt/kMaxOmega on top of the TELEMETRY_MODE selector and halt command).
    This commit replaces the file outright instead -- both of those additions
    are gone from this file as a result, requested explicitly and knowingly.
    [Stage4_FullLaw.ino]
2026-08-14 Rename firmware/3D model/Euler -> Gam
    The build never used Euler angles for control -- attitudeUpdate() has
    run on g_hat/gam end to end since it was written; eulerForTelemetry()
    only ever converted g_hat to roll/pitch for the Serial Monitor. The
    folder name next to Quaternion/ implied a competing representation
    that was never there. Renamed to Gam/, kept the telemetry helper as
    documented (read-only, never fed back into control).
2026-08-14 Add Phase 0 cube bring-up: single-moteus link, 3-moteus latency, IMU jitter
    Three new staged sketches under firmware/3D model/Gam/cube-bringup/,
    none of it adapted from the panel -- single-node CAN has no
    contention to measure, and the panel's estimator has no timing
    instrumentation. New code, same house style as the panel stages.
    - Stage0_SingleMoteusQuery: one wheel, SetStop/SetQuery/zero-torque
    in sequence, 60s, zero-error pass criterion (Phase 0.2). Uses the
    same Format-fixed torque command pattern documented in Firmware
    Lessons S2, with min_rcv_wait_us widened to 5ms so a slow reply is
    measured, not folded into "no reply" right at the 2ms boundary
    Stage0b is testing.
    - Stage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
    [Stage0_SingleMoteusQuery.ino, Stage0b_ThreeMoteusLatency.ino, Stage0c_IMUJitter.ino]
2026-08-14 Stage0_SingleMoteusQuery: add CAN controller state/error-counter diagnostics
    First bench run against real cube hardware: 0/11990 replies across all
    three phases (SetStop/SetQuery/zero-torque), zero exceptions. That's
    too uniform to be a timing problem -- either the bus is electrically
    dead or nothing is listening at kMoteusId=1, and the reply counts
    alone can't tell those apart.
    ACAN_T4 exposes exactly that distinction: controllerState() (kActive/
    kPassive/kBusOff) and receiveErrorCounter()/transmitErrorCounter().
    kBusOff means the Teensy's own transmitter gave up after repeated ack
    failures -- the signature of a missing termination resistor or a
    disconnected/miswired bus. Still kActive wit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
    [Stage0_SingleMoteusQuery.ino]
2026-08-14 Ignore /libraries/ -- was never meant to live in this repo
    Arduino IDE auto-installed Moteus/ACAN_T4/SparkFun_BMI270 into
    Cubli-Space-challenge-2026/libraries/ while its sketchbook setting was
    still (incorrectly) pointed at this repo -- a leftover from before that
    got fixed, not something anyone asked for. Deleted the untracked
    5.1MB copy; canonical installs already exist at
    ~/Documents/Arduino/libraries/. Ignored going forward in case the
    sketchbook setting regresses again.
2026-08-14 Fix moteus id <-> wheel-axis mapping: id 3=X, id 2=Y, id 1=Z
    Confirmed on the actual cube via Stage0_SingleMoteusQuery: id 3
    PASSED (20000/20000 replies, 0 errors, rt_us mean 984) and was
    independently identified by hand as the X-axis wheel. id 1 gave
    0/11990 replies with the CAN bus staying ACTIVE and zero errors the
    whole time -- confirming it was an addressing mismatch, not a bus
    problem (a dead/unterminated bus would show climbing tx errors and
    bus-off, not a clean zero).
    Every 3D-model file had the same wrong assumption (moteusX=1,
    moteusY=2, moteusZ=3) baked in from before any hardware existed to
    check it against -- fixed in all five places it appears: both Gam
    sketches (USB and WiFi)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
    [Skeleton_3Axis.ino, Skeleton_3Axis_WiFi.ino, Stage0_SingleMoteusQuery.ino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]
2026-08-14 Correct id<->axis mapping: id 2=X, id 3=Y (was reversed), id 1=Z
    Physically re-verified per wheel: the previous commit on this branch
    had id 3=X, id 2=Y from a verbal cross-check that turned out backwards.
    All three IDs now confirmed replying individually via
    Stage0_SingleMoteusQuery. id 1=Z was correct in both versions and
    stays unchanged.
    Same five files as before plus Stage0_SingleMoteusQuery.ino's own
    comment, which still referenced the old (wrong) mapping.
    [Skeleton_3Axis.ino, Skeleton_3Axis_WiFi.ino, Stage0_SingleMoteusQuery.ino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]
2026-08-14 Stage0b: add per-wheel reply tracking and CAN bus diagnostics
    First 10-min run: noReply was exactly 2x cycles on every 5s status
    line for 80+ seconds straight -- too regular for random bus
    contention, but the pooled counters can't say whether it's the same
    wheel losing every cycle or whether it rotates.
    Adds per-wheel reply/noReply counts (X/Y/Z broken out) and the same
    CAN controllerState()/error-counter diagnostic used in
    Stage0_SingleMoteusQuery, both in the periodic status line and the
    final summary.
    Working hypothesis recorded in the NOTES at the bottom: Moteus::Poll()
    dequeues one frame from the shared CanBus's receive queue per call and
    discards it if the source doesn't match that o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
    [Stage0b_ThreeMoteusLatency.ino]
2026-08-14 Stage0b: add a togglable inter-query delay as a diagnostic experiment
    Second run confirmed the pattern precisely: X=100% replies, Y=Z=0%,
    every cycle for the full run, CAN bus ACTIVE with zero errors
    throughout. Deterministic, not random -- whichever wheel is queried
    first in the loop wins, every time.
    Traced two candidate mechanisms in ACAN_T4's actual source, both
    plausible, can't distinguish from reading alone: (1) Moteus::Poll()
    dequeues one frame from the shared CanBus receive queue per call and
    discards non-matching frames (documented in Stage0b's NOTES already);
    (2) tryToSendDataFrameFD() uses exactly ONE dedicated hardware TX
    mailbox for CAN-FD data frames (not one per node), backed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
    [Stage0b_ThreeMoteusLatency.ino]
2026-08-15 Stage0b: resolve the 100/0/0 mystery -- single power supply, not software
    Root cause confirmed: only one moteus was actually powered at a time
    (single supply, moved between wheels between the two test runs), not
    all three simultaneously. Explains both runs at once, including why
    the winning wheel flipped (X, then Y) -- whichever unit had power that
    run ACKed every frame at the protocol level (hence CAN state ACTIVE,
    0 errors both times) but could only reply at the application layer
    for its own ID.
    Disabled kInterQueryDelayUs (was a diagnostic experiment, not needed)
    and updated the NOTES to record the resolution and demote the
    receive-discard / single-TX-mailbox theories to "real properties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
    [Stage0b_ThreeMoteusLatency.ino]
2026-08-15 Add edge bring-up: Y-wheel staged bring-up (Stages 1-5)
    Started ahead of Phase 4 (corner) because only one moteus (id 3,
    physically confirmed as the Y-axis wheel) has power right now -- full
    corner balance needs all three wheels soldered to the battery, edge
    only ever needed one. Same staged shape as the panel's Stage0-5
    (Firmware Lessons S7: repeat the progression "nearly unchanged"),
    adapted where the physics actually differs:
    - Stage1_YWheelSignCheck: isolated pulse, hand-held, determines
    kWheelSign for this wheel and (as a side effect, via measurement
    against both candidate gB vectors, not memory) which Y-edge is
    physically under the cube. Corrects a verbal mixup from earlier in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
    [Stage2_RateOnly.ino, Stage3_PositionDamping.ino, Stage4_FullLaw.ino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]
2026-08-15 edge-bringup: confirm kWheelSign = +1.0f across Stages 2-5
    Stage 1's isolated pulse test confirmed the placeholder was already
    correct for this wheel -- no flip needed, unlike every other sign/
    mapping question this session. Updated the comment in each stage to
    record the confirmation instead of leaving the "fix before flashing"
    warning in place.
    [Stage2_RateOnly.ino, Stage3_PositionDamping.ino, Stage4_FullLaw.ino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]
2026-08-15 Stage 2/3 confirmed working. Add kPhiOffset (4,5), remove velocity cap (4)
    Stage 2 armed and worked, Stage 3 "passes with flying colors" -- no
    code changes needed for either, the earlier "doesn't arm" report
    turned out to not need a fix.
    kPhiOffset, Stages 4 and 5: live-settable via "o<deg>", same
    convention as the panel's kThetaOffset, but a different kind of
    correction -- not a sensor/mount calibration (gMountDCM already
    handles that), a correction for this build's CURRENT physical resting
    point being genuinely offset from the designed equilibrium (2.544 deg
    measured, missing battery cable/DC-DC). Subtracted from phi_edge
    everywhere it's used (control, trips, arm gate, telemetry) so the
    0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
    [Stage4_FullLaw.ino, Stage5_Release.ino]
2026-08-15 edge-bringup: generalize all 5 stages to X/Y/Z axis selection
    Each stage now carries a single kAxis switch (enum Axis{AXIS_X,AXIS_Y,
    AXIS_Z}) that drives everything previously hardcoded to the Y wheel:
    - moteus CAN id (kAxisMoteusId[3] = {2,3,1}, physically confirmed
    id2=X, id3=Y, id1=Z), object renamed moteusY -> moteusActive
    - edge candidate table, now kCandidates[3][2] (one [+1,+1]/[-1,-1]
    pair per axis, values from cubli_gains.h's EDGE table), resolved by
    measurement against the active axis's two gB candidates as before
    - kWheelSign, now kAxisWheelSign[3] with only Y confirmed (+1.0f via
    Stage 1's pulse test); X/Z remain placeholders pending their own
    Stage 1 run
    - boot-time "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
    [Stage1_WheelSignCheck.ino, Stage2_RateOnly.ino, Stage3_PositionDamping.ino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]
2026-08-15 edge-bringup: leave kAxis on X (last hardware-validated config)
    All three edge/wheel combinations (X, Y, Z) now balance successfully
    through the staged bring-up -- confirms the axis-generalization from
    the previous commit holds across all three moteus ids, not just Y.
    kAxis left at AXIS_X in all 5 stages, matching the last hardware run.
    Switch back to AXIS_Y or AXIS_Z as needed per-file before uploading.
2026-08-15 edge-bringup: mark kAxisWheelSign CONFIRMED for X/Y/Z on all 5 stages
    User confirmed all three wheels balance on hardware without changing
    the wheel-sign default -- +1.0f is correct for X and Z, same as Y.
    Flips every kAxisWheelSign[3] entry (Stage1-5) and the README's
    wheel-sign section from PLACEHOLDER to CONFIRMED, and adds a
    "Hardware status" section documenting that all three edges/wheels
    have been run through the full staged bring-up successfully.
    [Stage1_WheelSignCheck.ino, Stage2_RateOnly.ino, Stage3_PositionDamping.ino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]
2026-08-16 corner-bringup: staged 5-file corner balance bring-up (X/Y/Z, all 8 corners)
    Same staged shape as edge-bringup and the panel before it, generalized
    from one active wheel to three coupled wheels:
    - Stage1_CornerIDAndPulse: 8-way corner ID by measurement (dot against
    cubli_gains.h's CORNER gB table), per-wheel open-loop pulse test with
    all three wheels commanded every cycle (two at zero torque). Carries
    forward kWheelSign=+1.0f for X/Y/Z, confirmed on hardware in
    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
2026-08-16 corner Stage4: tare-based phi offset + remove velocity cap
    Requested on hardware: Stage1-3 passed, but Stage4 can't arm -- still on
    the bench power supply (not the flight battery), so this build's real
    corner equilibrium sits measurably off cubli_gains.h's design gB, more
    than ARM_GATE's 0.5 deg. Same root cause edge-bringup hit on the Y edge,
    generalized to 3D:
    - "z1" tares gPhiOffset to whatever phi currently reads (z0 clears it).
    phi is a 3-vector here, so a typed-value fix like edge's kPhiOffset
    isn't practical -- tare captures the live measurement instead of
    needing three hand-typed degree values. Subtracted in
    updateCornerProjection() so every downstream use (control, arm gate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
    [Stage4_FullLaw.ino]
2026-08-16 corner-bringup: hardware milestone -- [+1,+1,+1]/[-1,-1,-1] balance
    Real hardware confirmation: the two best-lean corners (0.714/0.797 deg,
    the body-diagonal pair, smallest predicted lean of all 8 by a wide
    margin) both hold through Stage 4. The other six are mechanically
    unreachable on this build -- gravity leans the cube into wheel-to-frame
    contact at those orientations before the control law can act, a CAD/
    mount clearance issue, not firmware. Documented in the README's new
    Hardware status section rather than left as an open question.
    Also fixes a stale comment on kMaxOmega -- live-tuned on hardware to
    209.43951 rad/s (2000 RPM, the motor's actual rating) rather than
    literally uncapped;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
    [Stage4_FullLaw.ino]
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2026-08-18 corner-bringup: Stage4_AutoTrim -- automatic trim replaces manual z1/z0
    Copy of Stage4_FullLaw.ino with the manual snapshot-and-freeze phi offset
    (gPhiOffset, tared by hand with "z1") replaced by the closed-loop
    adaptive trim from "Automatic Trim -- Replacing the Hardcoded IMU
    Offset.md". Everything else -- control law, corner candidate table,
    friction FF, arm gate, loosened velocity cap -- is unchanged from that
    file.
    Mechanism: the standing wheel speed (already low-passed here at 5s tau,
    gRhoLp, previously telemetry-only) is a signed, calibrated measurement of
    the reference error -- K3's momentum-trading role means a constant
    reference error settles the wheel at a fixed speed instead of r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
    [Stage4_AutoTrim.ino]
2026-08-18 fine-tuning: operationalize Cube Fine-Tuning Test Plan's 7 tests
    Structure for the Test Plan doc, reusing what already exists plus new
    pieces for what didn't:
    Test 1 (FFT the tilt): fft_tilt_analysis.py's BANDS refined to match the
    Test Plan's table exactly (splits the old ">3 Hz" band into "2-3 Hz
    estimator phase lag" vs ">5 Hz loop rate/aliasing", which send you to
    different tests). Each hint now names the specific next test.
    Test 2 (estimator lag audit): a code read, done now against
    attitudeUpdate() in Stage4_AutoTrim.ino/Stage5_AutoTrim.ino (the same
    estimator since Stage 1). One concrete, previously-identified-but-never-
    applied finding fixed: every balance-stage file configured the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
    [Stage5_AutoTrim.ino]
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2026-08-19 Add rate low-pass filter to corner AutoTrim stages (hw-run-analysis.md 4.1/4.5)
    A 373.5s continuous corner-balance hardware run (auto-trim on) found
    torque saturating 71.8% of the time, driven by a ~35 Hz structural mode
    riding on the gyro signal, in phase across phi/om/u -- a resonant shape
    white noise cannot produce, and not attributable to a real disturbance
    (saturated vs unsaturated mean tilt were statistically identical). The
    1.3 Hz-bandwidth control loop cannot damp a 35 Hz mode, only feed it
    energy through K2 and the torque clamp in a closed loop that re-excites
    the mode every cycle.
    New files (Stage4_AutoTrim_RateFilter.ino, Stage5_AutoTrim_RateFilter.ino,
    copies of Stage4_AutoTrim.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
    [Stage4_AutoTrim_RateFilter.ino, Stage5_AutoTrim_RateFilter.ino]
2026-08-19 Update corner [-1,-1,-1]'s Kp for the new mass (1.633 kg) + strut plant
    User-supplied re-derived gain matrix for the corner-bringup rig's
    physical test corner (assumed [-1,-1,-1]: the historically-instrumented
    bring-up corner -- standing_speed_report.py's default K1/K3/ell are that
    corner's, and hw-run-analysis.md's 373.5s run was on it). Magnitude
    comparison also favors this identification: the new diagonal-block
    values (avg ~-7.02) sit much closer to the old [-1,-1,-1] entry
    (avg ~-6.89) than any other corner's old entry (next closest ~-7.13).
    ASSUMPTION FLAGGED IN EACH FILE'S COMMENT -- correct the corner label if
    wrong.
    Applied identically to all four AutoTrim-family files (Stage4_AutoT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
    [Stage4_AutoTrim.ino, Stage4_AutoTrim_RateFilter.ino, Stage5_AutoTrim.ino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]
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2026-08-19 Process 6 hardware test logs: corner rate-filter A/B + edge runs, report + plots
    Processed the 6 requested telemetry captures from FINAL/telemetry/serial/
    (1minCORNER_autotrim/lpf, PUSHES_CORNER_autotrim/lpf, 1minEDGE,
    EDGE6degrees) into docs/testing/Corner-RateFilter-and-Edge-Hardware-Tests
    -2026-08-19.md with 8 supporting plots.
    Key findings:
    - The autotrim-vs-rate-filter quiet-hold comparison is confounded on two
    axes and should not be read as a verdict on the filter: the two runs
    have different baseline (pre-filter) rate noise levels, and
    Stage4_AutoTrim_RateFilter.ino ships both the rate filter AND a faster
    trim-adaptation gain (k_a) in the same build, so the "wheels move less"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
    [Stage4_AutoTrim_RateFilter.ino, Stage5_AutoTrim_RateFilter.ino]
2026-08-20 Evaluate Kalman-filter rate estimation as the max-noise-rejection option
    Follow-up to the user-provided "Notch Filter and Adaptive Control --
    Evaluation.md", which concludes frequency-domain filtering (notch or
    low-pass) floors at ~88% of the torque clamp and names a Kalman filter
    on the reduced-attitude state as the only technique not bound by that
    floor. This evaluates what that actually takes.
    Theory (Section 1): a Kalman filter discriminates by consistency with a
    dynamics model, not by frequency -- the same trick the existing
    complementary filter already applies to ghat/phi (which is why phi is
    clean and w_b isn't). This is model-based rejection working inside the
    same frequency band si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
2026-08-20 Three new corner Stage 4 variants: fixed offset, no arm gate, +Kalman
    Implements the three requested firmware files, all built on the existing
    telemetry-integrated bases (Stage4_AutoTrim.ino, Stage4_AutoTrim_
    RateFilter.ino):
    1. Stage4_FixedOffset.ino -- copy of Stage4_AutoTrim.ino with gTrim's
    live adaptation replaced by kPhiOffset, a compile-time constant
    derived from perfect_equilibrium_2.log's converged trim (mean over
    132.41s continuous armed hold, std<0.0012 deg/axis -- a genuine fixed
    point, not a snapshot). The arm gate (kArmGate, refusing "a1" unless
    already within 0.5 deg of equilibrium) is removed -- "a1" arms
    unconditionally now. This is a real safety tradeoff,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
    [Stage4_FixedOffset.ino, Stage4_FixedOffset_Kalman.ino, Stage4_FixedOffset_RateFilter.ino]
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2026-08-20 Fix Kalman filter NaN divergence -- root cause of "won't arm" on WiFi build
    Diagnosed from the WiFi build's own telemetry (session_corner_20260820_
    160635.log, _160822.log, _161459.log): om_x/y/z_filt_dps and mode_x/y/z_dps
    were "nan" from within ~10s of boot, on every session. commandWheels()'s
    existing isfinite(u) check correctly caught the resulting NaN torque and
    disarmed -- so no unsafe torque was ever commanded -- but nothing printed
    and there was no recovery path short of a reboot, which at the terminal
    looks exactly like "it detects the arm but doesn't respond correctly."
    The arm gate itself was already confirmed removed in both files (no
    kArmGate, unconditional "a1") -- that was ne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
    [Stage4_FixedOffset_Kalman.ino]
2026-08-20 Fix Kalman filter forward-Euler instability -- the real cause of "goes bananas" on arm
    Field report after the earlier NaN-divergence fix: correct corner
    ([-1,-1,-1]), sub-1-degree placement at arm, still diverges hard. That
    fix addressed a symptom (NaN-lock under an anomalous dt spike); this is
    the actual disease, and it needs no timing anomaly to trigger.
    updateModeKalman()'s (eta, eta_dot) mode-oscillator block was integrated
    with forward Euler. Forward Euler applied to a lightly damped oscillator
    is only stable for dt < 2*zeta/wn -- at this file's own compiled-in
    defaults (35 Hz, zeta=0.05) that's 0.46ms, 4.3x smaller than the loop's
    ordinary 2ms period. Checked by direct eigenvalue comp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
    [Stage4_FixedOffset_Kalman.ino]
2026-09-17 Restructure as a portfolio repository
    The repo had grown into a working directory: 77 sketches across four levels of
    PreFINAL/FINAL/USBMODE/WIFIMODE nesting, 187 MB of raw telemetry, a README
    claiming the project was "simulation-only" with "no physical build" while the
    tree contained 373 s corner-balance logs, and the entire 3D Simscape design
    chain missing.
    Structure
    - Promote the five bring-up ladders out of the nested tree: panel, cube, edge,
    corner and link bring-up are now top-level under firmware/.
    - matlab/ becomes simulation/, split into panel-2d/ and cube-3d/.
    - New data/ (curated telemetry), figures/ (all plots and media), docs/README.md.
    - Remove spaces and em-dashes from every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
    [Cubli_Frame_Final.step, Cubli_Xwheel_Final.step, Cubli_Ywheel_Final.step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]
2026-09-17 Stop tracking local Arduino library symlinks
    The rewritten .gitignore dropped the /libraries/ rule the original had, so
    three symlinks got committed. They point at absolute paths under
    ~/Documents/Arduino/libraries, so they are broken for any other clone. Rule
    restored; the local symlinks are untouched.
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
